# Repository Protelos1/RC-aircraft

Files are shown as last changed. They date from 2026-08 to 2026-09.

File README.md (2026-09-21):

# RC-aircraft
**SKYLITE-RC PLANE** 

This project is designed as a small, durable, repairable fixed wing rc plane for flying in limited space and tinkering with!

It is also designed to inspire and help other people develop aviation/rc based projects.



## **Message for reviewer:** The second shortest journal reccord which doesnt have an image or over 100+ words you can disregard as i cant make it go away, I have moved this project over from stardance and i have added the time i spent and the lapses but its not redgistering, and issues you can dm me if you want.

---------
Features:
---------
- Manuvers well in the air
- Easy to maintain and fix
- Parachute system for emergencies with easy deployment --- will be done after initial airframe is tested and built ---
- Made out of cheap and durable foamboard
- Durable to survive rough landings and small scuffs

# Design Preview

### Front Image


### Side View


### Wing Rib


### Wiring Diagram


-------------------------------------------------------------------------------------------------------------------------------------------------------------------
# Why An Rc Plane?
-------------------------------------------------------------------------------------------------------------------------------------------------------------------

The idea came from looking at rc planes online, you buy the product set it up and use it then something goes wrong a bit breaks or you do a hard landing... and you dont know how the product really works you just turned it on and then flew it.

With my project you build your plane from the ground up designing where you want each component and each design choice has an actual impact. 
Do i want a high or a low wing? for example. When you are learning to fly RC you crash and as you understand the plane and how it works you can fix it easier and properly.

With a model you buy online it costs so much to replace and wasteage as you have to replace the whole airframe. But with mine you can salvage the electronics and make a new airframe out of some depron foam and whats that going to cost you a couple £/$.

# Image Gallery

### Bulkead


### Battery Holder to maintain CG (centre of gravity)


### Servo Holder (9g)


### Basic control Horn


### BOM
Is in the files list under BOM.cvs

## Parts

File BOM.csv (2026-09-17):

Name | product | TOTAL price gbp | TOTAL price USD | notes | Quantity | link
Transmitter | RadioMaster pocket |  |  | BUYING MYSELF | 1
servos 9g | 9g metal servos | 3.85 | 5.23 | metal gears for reliability | 1 (packs of 5 servos) | https://a.aliexpress.com/_Ev55wdU
Reciver | Radiomaster ER4 4CH ELRS Receiver | 14.99 | 20.38 | 4ch reciver | 1 | https://www.hobbyrc.co.uk/radiomaster-er4-4ch-elrs-receiver
motor | 2200kv Brushless motor | 9.14 | 12.43 | Brushless motor | 1 | https://a.aliexpress.com/_EvxbNnM
esc | ESC 30a. 2-3s | 12.7 | 17.27 | speed controller | 1 | https://www.hobbyrc.co.uk/t-motor-at-30a-2-3s-fixed-wing-esc
batteries | 680mAh batteries | 16.5 | 22.43 | batteries | 1 | https://www.hobbyrc.co.uk/betafpv-lava-ii-2s-95c-lihv-batteries-xt30
depron foam | depron style foam | 8.88 | 12.07 | foam 6mm | 2 | https://www.sarikhobbies.com/product/depron-white-6mm-x-625mm-x-800mm-single-sheet/
transmitter batteries | transmitter batter5 | 11.99 | 16.3 | 18650 batteries | 1 | https://www.hobbyrc.co.uk/radiomaster-3200mah-18650-cells-2pcs
propeller | propellor | 5.03 | 6.84 | propeller pack 6030 6inch | 1 | https://a.aliexpress.com/_EGrKo6W
 |  | £83.08 | 113
 |  |  | add $5 for delivery fees
 |  |  | $118

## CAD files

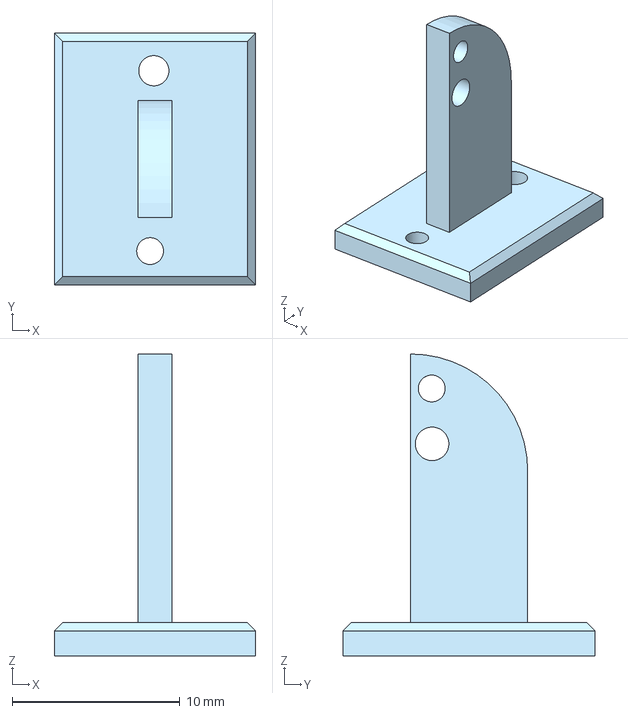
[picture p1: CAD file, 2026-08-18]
cad/Control Horn.step
12.0 x 15.0 x 18.0 mm

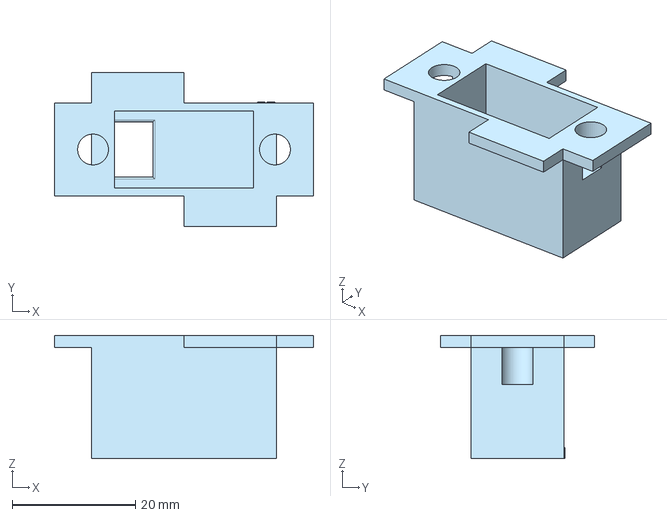
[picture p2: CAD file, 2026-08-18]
cad/Servo Tray.step
42.0 x 25.0 x 20.0 mm

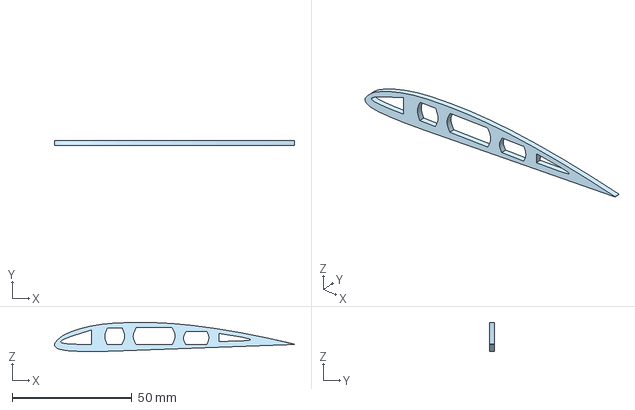
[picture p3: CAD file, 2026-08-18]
cad/Wing Rib.step
100.0 x 2.00 x 12.2 mm

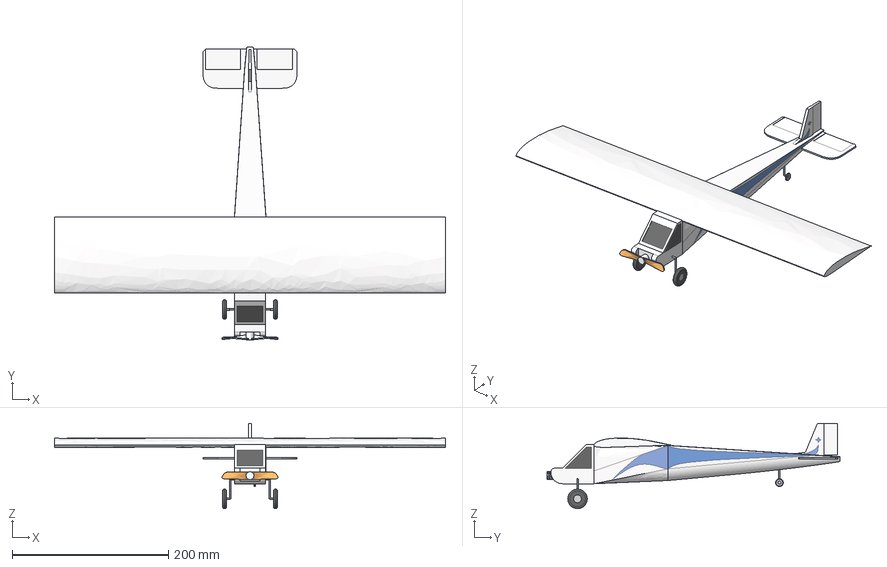
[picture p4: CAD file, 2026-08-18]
cad/RC Plane.step
500.0 x 374.9 x 109.1 mm

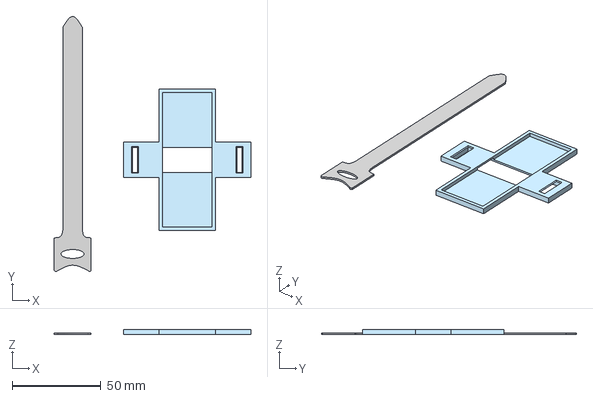
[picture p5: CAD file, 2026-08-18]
cad/Battery Tie down DO NOT PRINT ZIP TIE.step
111.3 x 144.0 x 3.00 mm

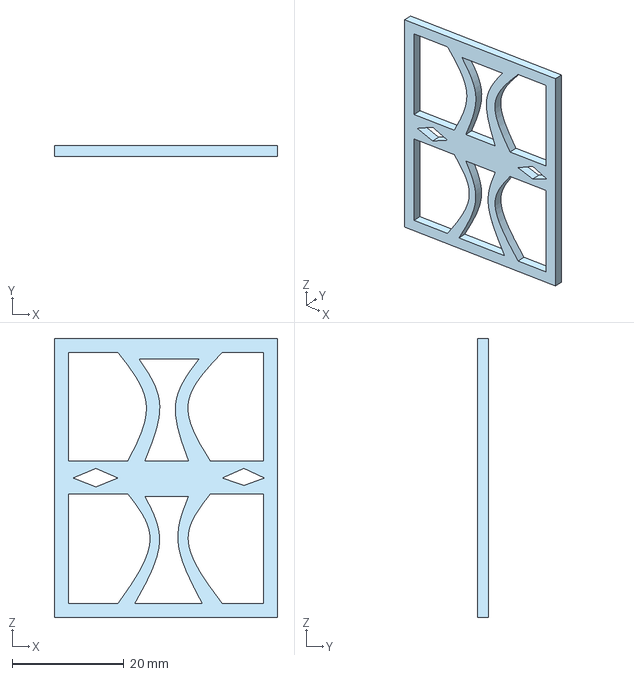
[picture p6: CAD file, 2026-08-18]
cad/Bulkhead.step
40.0 x 2.00 x 50.0 mm

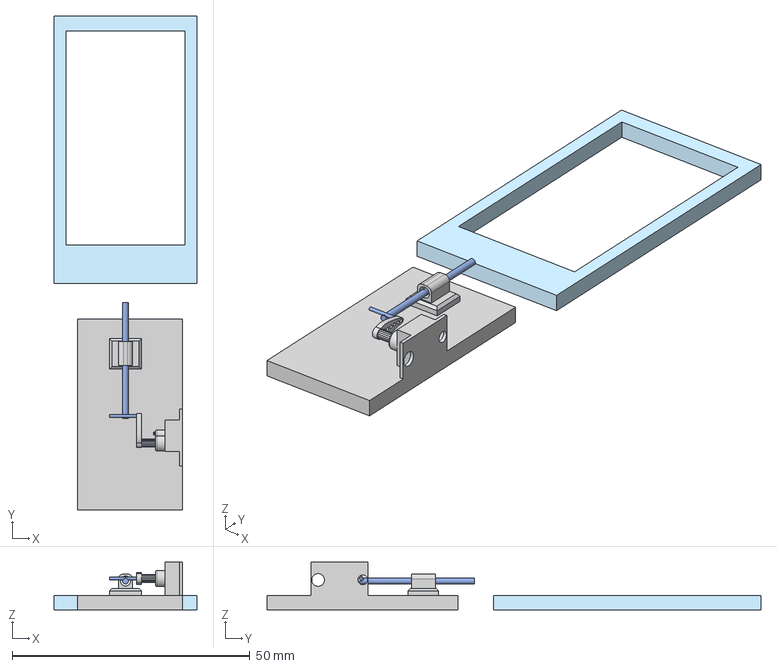
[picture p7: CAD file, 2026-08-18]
cad/Parachute Release (Dont print).step
30.0 x 103.9 x 10.0 mm

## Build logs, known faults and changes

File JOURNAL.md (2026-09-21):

Journal.md

1h 8m  Total : 9h 14m
bom rc plane
**Skylite \- BOM**  
I will be submitting for funding of the parts\!\!\!

## BOM \- Link (let me know via a comment if it doesn't work (it should)) ##

## Finished up the Bill of materials and i also just changed the github made it look better e.c.t ##

Things i had to think about today  
I made sure all the parts fit and worked with each other connectors brands e.c.t.  
I have fully committed to ELRS (ExpressLRS for the radio)  
I have considered battery weight vs power and how that will affect the aircraft and also considered the weight of the aircraft and the power produced by the motor.

1h 2m   Total : 8h 6m
battery holder rc plane
rib rc plane
bulkead rc plane

**Today i worked on some essential pieces of design for the LiteSky airframe\!**  
I have created  
1)A battery holder to stop it moving around and affecting weight in flight  
2\) A wing strut that will go between the pieces of depron foam to give it support and also that Clark Y airfoil shape  
3\) A internal bulkhead this strengthens the inside of the cabin for landings and help everything stay connected.  
---

Design bits:  
You will notice how the wing strut and the bulkhead have cutouts in them this is to reduce the weight as much as possible. I had to be careful that it did not weaken the integrity of the pieces so that they can complete what they are designed for.  
---

The battery tray holder was especially designed for reusable cable ties to thread through and under the battery holder.  
You may have to use 2 ties depending on battery size.  
But the holder has a specific under channel to allow the tie to sit flush with the plastic and being allowed to be glued down inside the aircraft.

38m  Total : 7h 4m
wiring rc plane

Worked on the place where the components will go and how they will be wired together.  
Things i had to think about:  
---

1. Spacing out components and sitting the heavier ones in the correct location for weight and balance.  
2. I had to think about the CG (centre of gravity) this should be at the peak thickness of the wing or in my case 3cm from the leading edge.  
3. Also had to think about components getting hot and allowing them enough airflow.

---

And also what fastening system to use for the hatch to access the battery…  
Magnets… a bit heavy  
Tape….. a bit weak  
Ziptie…… impractical  
A 3d printed locking mechanism\!\!\!

3h 5m  Total : 6h 26m
plane rc plane
rc plane in construction

Rc plane \- Final design\!\!\!\!  
Woah that took a while lol.  
**You can scroll through the images to see it in progress and then the finished model.**  
I have finished iteration 1 of the final design for the Rc plane\!  
The only things i expect to change now to this model is maybe a couple of diameters but apart from that i think all of the major work for the design is done.  
These are the things i ‘researched’ and considered during the design process  
1  
The wing type  
For a rc plane lift is important as well as simplicity when making this it is hard to make wing designs that fold and bend this is why i have chosen the **’Clark Y** aerofoil design. This design is used on GA (general aviation \- small planes like cessna e.c.t) and is also extremely common in other RC planes.  
2  
I have also considered the **DIMENSIONS** for this aircraft  
The wing is 50cm long and 10cm wide and in person it will be 1.2 cm thick (at the thickest point)  
The horizontal stabilizer (the mini wing at the back)  
Is 7.5 cm on each side so 15cm in total  
The cabin/fuselage is 37.5 cm **75%** of the wingspan  
**And out all important target weight is under 250g**  
3  
WING DESIGN  
It is a high wing design for stability in the air and is normally considered the easiest design to fly.  
It is 12% of chord which is 1.2cm max thickness at the biggest point  
The Peak of the thickness will be 3cm behind the leading edge (front of the wing)  
4  
**THE CABIN**  
The cabin is designed to be 4cm along and 5cm height to allow for LiPo batteries receivers and ESC (Speed controller \- flight computer)  
5  
**LANDING GEAR**  
The landing gear is in a traditional tail dragger design with a rear wheel  
The stance of the gear will be at a forward and downward angle so the wheels sit slightly ahead of the wings leading edge to prevent flipping over also to absorb max impact without breaking  
As well as the gear i am going to test belly landings (landings with no gear) they have to be preformed on something soft grass for example. But because the plane is so light belly landings should not be an issue.

1hr 29m Total : 3h 5m
component diagram

Improving git hub for rc plane adding component diagrams e.c.t  
And working out how to wire the components together.

34m  Total : 1h 52m
servo holder

Rc Servo Holder (Modeled the rc servo holder to fit the standard 9g servo in onshape) 

43m Logged Total : 1h 18m
parachute rc plane

Servo System For parachute mottled in onshape and it is a mock up design not a thing to print.

35m Logged  
control horn rc plane

Control horn for control surfaces and quick mockup of vague ideas of what the plane will look like.

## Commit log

2026-08-12 Create BOM
2026-08-12 Update BOM
2026-08-14 Update STL-Files
2026-08-18 Create Cad
2026-09-10 Update and rename BOM to BOM.cvs
2026-09-17 Rename Rc bom - Sheet1.csv to Rc bom.csv
    [Rc bom.csv]
2026-09-21 Rename Rc bom.csv to BOM
2026-09-21 Rename BOM - Sheet1.csv to BOM.csv
    [BOM.csv]
